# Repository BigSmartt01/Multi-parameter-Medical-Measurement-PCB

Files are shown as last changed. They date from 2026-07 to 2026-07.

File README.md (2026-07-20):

# Multi-Parameter Patient Monitoring System

**Project Topic:** Design and Development of a Multi-Parameter Patient Monitoring System with ECG Arrhythmia Detection, Real-Time Data Storage, and Wireless Remote Display.

This repository holds the hardware design (schematic, PCB, footprints, fabrication files) for the patient-side sensor and actuator unit. Firmware and the ML/logic layer on the Raspberry Pi are maintained separately by the software team; this repo covers circuitry only.

## What this device does

The board sits at the patient's bedside and handles all direct sensor and actuator interfacing:

* Reads ECG (AD8232), SpO2/pulse (MAX30102), body temperature (DS18B20), and blood pressure cuff pressure (MPXHZ6400).
* Drives a pump and a solenoid/valve for the blood pressure cuff inflate/deflate cycle.
* Displays local status on a 2.4" OLED and gives audible alerts through a buzzer.
* Streams sensor data wirelessly and receives commands over WiFi/MQTT.

The Raspberry Pi 5 sits on the nurse side, runs the ML model (arrhythmia detection), logic, data storage, and drives an HDMI display plus a web app. It never touches the patient directly, all sensor/actuator interfacing is the ESP32's job.

## System architecture (high level)

```
\[Patient side]                              \[Nurse side]
ESP32 (sensors + actuators + OLED + buzzer)  <--MQTT/WiFi-->  Raspberry Pi 5 (ML, logic, storage, HDMI, web app)
```
<p align="center">
    
</p>

MQTT topic structure (for reference, implemented in firmware):

Pi publishes (commands to ESP32):

* `pi/control/pump`
* `pi/control/valve`
* `pi/display/oled`
* `pi/control/buzzer`

Pi subscribes (data from ESP32):

* `esp32/sensors/ecg`
* `esp32/sensors/bp`
* `esp32/sensors/temp`
* `esp32/sensors/pulse`
* `esp32/status/pump`

A full block diagram will be added to `docs/` covering both the electrical and system-level data flow.

## Repository structure

```
Multi-parameter Medical Measurement/
|-- libraries/
|     |-- 3d          (3D models for footprints, if used)
|     |-- footprints   (custom KiCad footprints, e.g. module outlines)
|     |-- symbols      (custom KiCad symbols for breakout modules)
|-- fabrication         (gerbers, drill files, BOM, pick-and-place, for JLCPCB)
|-- kicad                (project file, schematic, PCB layout)
|-- docs                 (this documentation, block diagrams, reference notes)
```

## Hardware summary

|Subsystem|Part|Notes|
|-|-|-|
|MCU|ESP32 DevKit V1 (30 GPIO)|Mounted on female header for clearance|
|ECG|AD8232 breakout|LO+/LO- leads-off detection wired in|
|SpO2 / Pulse|MAX30102 breakout|I2C|
|Temperature|DS18B20|1-Wire, 4.7k pull-up|
|Blood pressure|MPXHZ6400AC6T1|SOIC-8, resistor divider scales output for ESP32 ADC|
|Display|2.4" OLED, SPI, 7-pin|CS tied to GND (only SPI device on board)|
|Alert|Piezo buzzer|Driven through BC337 NPN transistor stage|
|Pump|12V, MOSFET-switched|IRLB8721, flyback diode, gate pull-down|
|Solenoid/Valve|12V, MOSFET-switched|IRLB8721, flyback diode, gate pull-down|
|Power|3x 18650 (3S) + BMS|12.6V nominal, LM2596 module steps down to 5V|

Full pin mapping and design rationale are in [`docs/circuit\_documentation.md`](docs/circuit_documentation.md).

<p align="center">
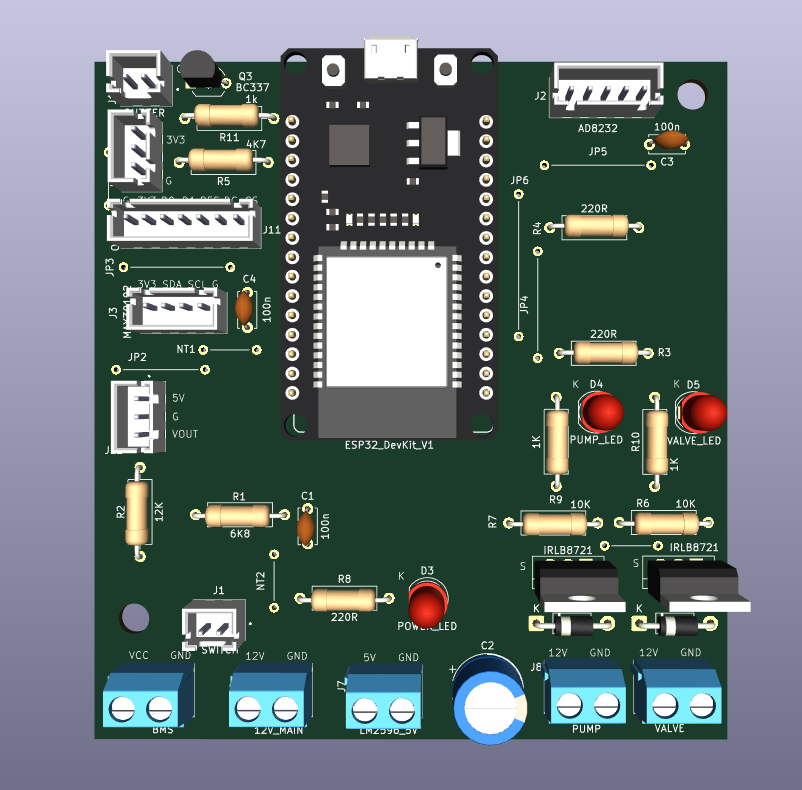
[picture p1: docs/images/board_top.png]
  <br>
  <em>Fabricated single-layer patient-side monitoring board</em>
</p>

## Power architecture

<p align="center">
  
</p>

<p align="center">
  <em>3x 18650 (3S) + BMS -> LM2596 buck -> 5V rail</em>
</p>

## Getting started

1. Open `kicad/Multi-parameter Medicals.kicad\_pro` in KiCad 9.0.7 or later.
2. Custom symbols and footprints for breakout modules (AD8232, MAX30102, LM2596 module, BMS module) live under `libraries/`, make sure these are added to your project's library table before opening the schematic, or KiCad will show missing symbol/footprint errors.
3. The board is single-layer, routed with net ties and jumper wires (JP1-JP6, NT1-NT3) to work around single-layer constraints. If you're re-routing, keep the ground pour intact between the analog sensor section (left side) and the motor/switching section (right side), see the documentation for why.
4. Before sending to fab, run a full DRC pass and verify trace widths on the high-current nets (battery/BMS input, pump, solenoid) against actual component current ratings.

## Team

Circuit design (schematic + PCB): Smart Ayodele
Firmware and ML/logic: student team

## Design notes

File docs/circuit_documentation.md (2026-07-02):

# Circuit Documentation: Multi-Parameter Patient Monitoring System

This document explains the schematic and PCB design decisions for the patient-side hardware unit. It's meant as a reference for anyone working on this board, whether debugging, modifying, or just trying to understand why something was wired the way it was.

Project topic: Design and Development of a Multi-Parameter Patient Monitoring System with ECG Arrhythmia Detection, Real-Time Data Storage, and Wireless Remote Display.

---

## 1. System overview

The board is the patient-facing sensor and actuator unit. It does not run any ML logic, does not store data long-term, and does not drive the main display, all of that is handled by a Raspberry Pi 5 on the nurse side. The ESP32 on this board's only jobs are:

1. Read four physiological parameters (ECG, SpO2/pulse, temperature, blood pressure via cuff).
2. Control the pump and solenoid/valve for the BP cuff inflate/deflate cycle.
3. Show local status on an OLED and sound a buzzer for local alerts.
4. Talk to the Raspberry Pi wirelessly (WiFi/MQTT), sending sensor data out and receiving control commands in.

Communication between the ESP32 and the Raspberry Pi is entirely wireless, so it does not add any circuitry to this board, it's handled by the ESP32's onboard WiFi.

---

## 2. Power architecture

```
3x 18650 (series) --> 3S BMS --> Push Button Switch --> [12V rail]
                                                            |
                                                            +--> Pump / Solenoid (via MOSFETs)
                                                            |
                                                            +--> Pump LED, Solenoid LED
                                                            |
                                                            +--> LM2596 buck module --> [5V rail]
                                                                                          |
                                                                                          +--> ESP32 VIN
                                                                                          +--> MPXHZ6400 pressure sensor
                                                                                          +--> Power LED

ESP32 onboard 3.3V LDO --> [3V3 rail] --> AD8232, MAX30102, DS18B20, OLED, Buzzer
```

**Why this split:** The pump and solenoid are the highest current draw items on the board and run directly off 12V rather than through the buck converter, this keeps the LM2596 sized only for what the 5V rail actually needs (ESP32 + pressure sensor), and avoids putting motor switching transients through the same regulator that's trying to hold a clean 5V for an analog sensor.

**BMS:** 3S configuration matches the three series 18650 cells, handles balancing and over-discharge/overcurrent protection.

**Bulk capacitance:** A 1000uF capacitor (C2) sits at the LM2596 output to absorb transients, particularly important given the pump/solenoid switching nearby can cause momentary sag on the input side that would otherwise ripple through to the 5V rail.

---

## 3. Sensor interfacing

### 3.1 ECG (AD8232) — J2

| Pin | Net | ESP32 GPIO |
|---|---|---|
| 3V3 | 3V3 | — |
| ECG_OUT | ECG signal | GPIO34 (ADC1_CH6, input-only) |
| LO- | Leads-off negative | GPIO33 |
| LO+ | Leads-off positive | GPIO32 |
| GND | GND | — |

A 100nF decoupling capacitor (C3) sits at the 3V3 supply pin of J2, added specifically because this board also carries motor-switching circuitry, the cap is local insurance against supply noise reaching the ECG front end.

**LO+/LO- matter.** These are digital outputs from the AD8232 that go HIGH when an electrode has detached from the skin. Without reading them, a loose lead produces garbage or flatline data indistinguishable from an actual reading, both for the arrhythmia detection model and for anyone monitoring the signal. They're read as simple digital HIGH/LOW inputs in firmware.

### 3.2 SpO2 / Pulse (MAX30102) — J3

I2C device, shares the bus with nothing else on this board (OLED is SPI, not I2C).

| Pin | Net | ESP32 GPIO |
|---|---|---|
| 3V3 | 3V3 | — |
| SDA | I2C data | GPIO21 |
| SCL | I2C clock | GPIO22 |
| GND | GND | — |

A 100nF decoupling cap (C4) is present at the 3V3 pin, same rationale as the ECG module.

### 3.3 Temperature (DS18B20) — J4

1-Wire device.

| Pin | Net | ESP32 GPIO |
|---|---|---|
| 3V3 | 3V3 | — |
| TEMP | Data | GPIO4 |
| GND | GND | — |

R5 (4.7k) is a pull-up resistor between 3V3 and the TEMP data line, required by the 1-Wire protocol.

### 3.4 Blood pressure / cuff pressure (MPXHZ6400AC6T1) — IC1

This is a bare SOIC-8 sensor IC, not a breakout module, so it needs its own supply and signal conditioning on this board.

**Pinout note:** only VS (supply), GND, and VOUT are connected. Pins DNC_1 through DNC_5 (5 of the 8 pins) are internal device connections per the datasheet and must not be connected to anything, including ground.

**Signal conditioning:** the sensor's raw output swings up to roughly 4.7V at full scale (5V supply), which exceeds the ESP32 ADC's 3.3V input limit. A resistor divider scales this down before it reaches GPIO35:

```
VOUT --[R1: 6.8k]--+--[R2: 12k]-- GND
                    |
                    +-- C1 (100nF) -- GND
                    |
                    BP_OUT --> GPIO35 (ESP32 ADC, input-only)
```

At the sensor's absolute worst-case output (4.7V), this divider brings the signal down to roughly 3.0V, safely under the ADC limit even in an overpressure fault condition. The 100nF capacitor (C1) filters switching noise picked up on the line before it reaches the ADC, added specifically because of the pump/solenoid switching happening elsewhere on the board.

**Assembly note:** this is the only SMD component on an otherwise all-through-hole board. It's SOIC-8 package with 1.27mm pin pitch, hand-solderable with a normal fine-tip iron. J12 (BP_JST) is included as a fallback in case the team decides to source a pre-assembled breakout module instead of hand-soldering the bare IC, either path works with this board.

---

## 4. Actuator interfacing (Pump and Solenoid/Valve)

Both follow an identical MOSFET low-side switching pattern.

```
GPIO --[220R gate resistor]-- MOSFET Gate
                               |
GND --[10k pull-down]---------+
                               
MOSFET Drain -- Load (Pump or Solenoid) -- 12V
MOSFET Source -- GND

Flyback diode: cathode to 12V, anode to switched node (across the load)
```

| Actuator | MOSFET | Gate GPIO | Gate resistor | Pull-down | Flyback diode |
|---|---|---|---|---|---|
| Pump | Q1 (IRLB8721) | GPIO26 | R3 (220R) | R7 (10k) | D1 (1N4007) |
| Solenoid/Valve | Q2 (IRLB8721) | GPIO27 | R4 (220R) | R6 (10k) | D2 (1N4007) |

**Why IRLB8721:** logic-level MOSFET, fully enhanced well under 3.3V gate drive, so it switches cleanly straight off an ESP32 GPIO through the gate resistor without needing a separate gate driver IC.

**Why the gate pull-down (10k):** during ESP32 boot/reset, GPIOs can float momentarily. Without the pull-down, a floating gate could let the MOSFET partially conduct unintentionally. The pull-down holds the gate at GND (MOSFET off) until firmware actively drives it high.

**Why the flyback diode:** both the pump and solenoid are inductive loads. When the MOSFET switches off, the collapsing magnetic field generates a voltage spike that can exceed the MOSFET's rated drain-source voltage and destroy it. The flyback diode gives that current a safe path to circulate (cathode to 12V, anode to the switched node) rather than spiking through the MOSFET.

**Indicator LEDs:** D4 (pump) and D5 (solenoid) are wired in parallel across each load's switched node, so they light whenever that actuator is energized, no separate GPIO or logic needed. 1k current-limiting resistors (R9, R10) since these run off the 12V rail.

---

## 5. Display and alert

### 5.1 OLED (2.4", SPI, 7-pin) — J11

| Pin | Net | ESP32 GPIO |
|---|---|---|
| 3V3 | 3V3 | — |
| D0 | SPI Clock | GPIO18 |
| D1 | SPI MOSI | GPIO23 |
| RES | Reset | GPIO16 |
| DC | Data/Command | GPIO17 |
| CS | Chip Select | Tied to GND |
| GND | GND | — |

**Note on CS:** normally CS would be driven by a GPIO (GPIO5 in early revisions of this design), but since this OLED is the only SPI device on the board, CS is tied permanently to GND instead. This is standard practice for single-device SPI buses, it saves a GPIO and works because there's no bus contention to arbitrate.

### 5.2 Buzzer — J10

The buzzer is not driven directly off a GPIO. GPIO pins can't reliably source enough current for most buzzers, so it goes through an NPN transistor low-side switch:

```
3V3 -- Buzzer(+)
Buzzer(-) -- Q3 Collector (BC337)
GPIO25 --[R11: 1k]-- Q3 Base
Q3 Emitter -- GND
```

GPIO25 through the 1k base resistor is enough to saturate the BC337 and switch the buzzer on/off cleanly, without stressing the GPIO pin regardless of the buzzer's actual current draw.

---

## 6. Complete GPIO map

| GPIO | Function | Notes |
|---|---|---|
| 4 | DS18B20 temperature data | 4.7k pull-up (R5) |
| 5 | (unused — CS net grounded instead) | See OLED section |
| 16 | OLED RES | |
| 17 | OLED DC | |
| 18 | OLED D0 / SPI CLK | |
| 21 | MAX30102 SDA | I2C |
| 22 | MAX30102 SCL | I2C |
| 23 | OLED D1 / SPI MOSI | |
| 25 | Buzzer (via Q3 base) | |
| 26 | Pump gate | via R3/R7 |
| 27 | Solenoid/Valve gate | via R4/R6 |
| 32 | AD8232 LO+ | |
| 33 | AD8232 LO- | |
| 34 | AD8232 ECG output | ADC1, input-only |
| 35 | Blood pressure sensor output | ADC1, input-only, via divider |

9 functional GPIOs in active use, well within the ESP32's available pin count, leaving room for future additions.

---

## 7. PCB layout notes

### 7.1 Single-layer constraint

This board is routed on a single copper layer, using jumper wires and net ties (JP1-JP6, NT1-NT3) to bridge connections that would otherwise require a second layer. This is a deliberate cost/complexity tradeoff for a student-fabricated board, but it means routing discipline matters more than it would on a 2-layer design, particularly around ground continuity.

### 7.2 Placement zones

The board is organized into two zones kept physically separated:

- **Sensor/signal side (left):** AD8232, MAX30102, DS18B20, OLED, and their associated JST connectors.
- **Power/switching side (right/bottom):** MOSFETs, flyback diodes, gate resistors, LM2596, BMS input, screw terminals for pump/solenoid.

This separation exists to keep switching noise from the pump/solenoid MOSFETs away from the sensitive analog ECG and pulse signals. The AD8232 connector (J2) in particular was originally placed too close to the MOSFET cluster during early layout and was moved as part of the design review, keep this in mind if the board is ever re-laid-out, that adjacency is the single most noise-sensitive placement decision on the board.

### 7.3 Ground pour

A single ground pour is used across the board (not split analog/digital grounds). This works because of placement discipline rather than pour topology: high-current return paths (motor switching) are kept geometrically away from the direct line between sensor connector grounds and the main ground return, so a shared pour doesn't inject switching noise into the sensor grounds under normal operation. If ECG readings show noise correlated with pump/solenoid activity during testing, the fix is more likely a ferrite bead on the AD8232 supply line than a ground pour rework.

### 7.4 ESP32 antenna keepout

The ESP32 DevKit module has a WiFi antenna area that needs to stay clear of copper pour, traces, and components, both on this board and in whatever enclosure houses it. Check the specific antenna zone on the module's silkscreen/datasheet and maintain that keepout, this matters more here than on a typical project since the board relies on continuous bidirectional WiFi/MQTT communication.

### 7.5 Before fabrication

- Run a full DRC pass, the jumper/net-tie routing is dense in places and worth double-checking for accidental bridges or unintended opens.
- Verify trace widths on high-current nets (battery/BMS path, pump, solenoid) against the actual rated current of the pump and solenoid being used, not just an assumed default.
- Confirm mounting hole placement against the enclosure design.
- Do a 3D/clearance check, especially around densely packed clusters, to make sure hand soldering and wire access to screw terminals is realistic.

---

## 8. Bill of Materials highlights

Full BOM is exported from KiCad under `fabrication/`. Key parts requiring careful sourcing:

| Part | Why it matters |
|---|---|
| MPXHZ6400AC6T1 | SOIC-8, only 3 of 8 pins connected, verify pinout against datasheet chamfer/pin-1 marking before soldering |
| IRLB8721 (x2) | Logic-level MOSFET, confirm TO-220 pinout (G-D-S) matches datasheet, pinout can vary by manufacturer even within the same package |
| 1N4007 (x2) | Flyback diodes, orientation is safety-critical: cathode to 12V, anode to switched node |
| BC337 | Buzzer driver transistor |
| LM2596 module | Assumed to be the ready-made module (has onboard Schottky diode and inductor), not the bare IC |

---

## 9. Revision notes

Rev 1.0, dated 2026-07-01. Diode orientation, buzzer driver, and MOSFET/AD8232 placement were reviewed and corrected during design review prior to this revision. See open items in the repository README for outstanding checks before fabrication.

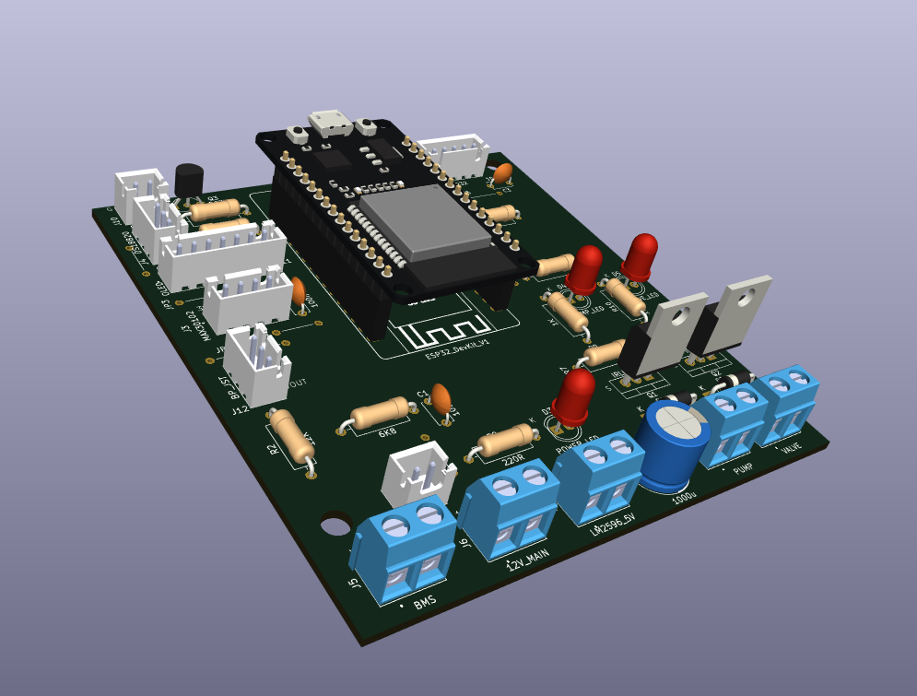
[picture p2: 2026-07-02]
docs/images/3D_04.png

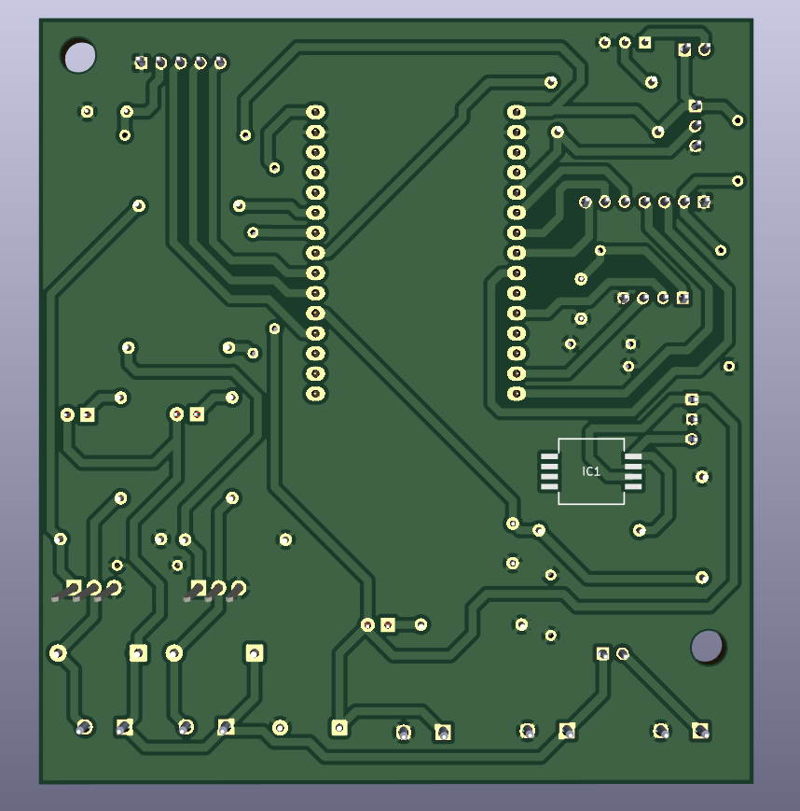
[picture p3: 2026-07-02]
docs/images/board_bottom.png

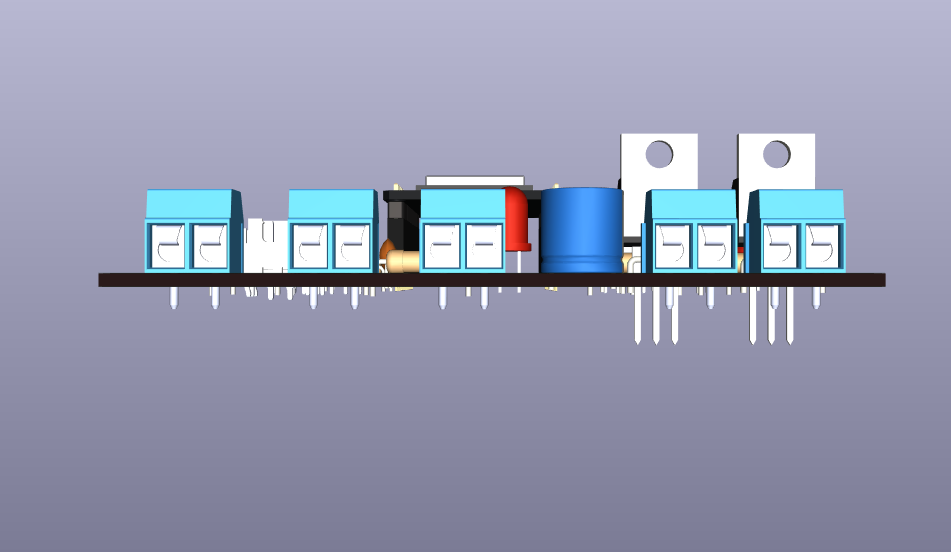
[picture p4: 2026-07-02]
docs/images/3D_03.png

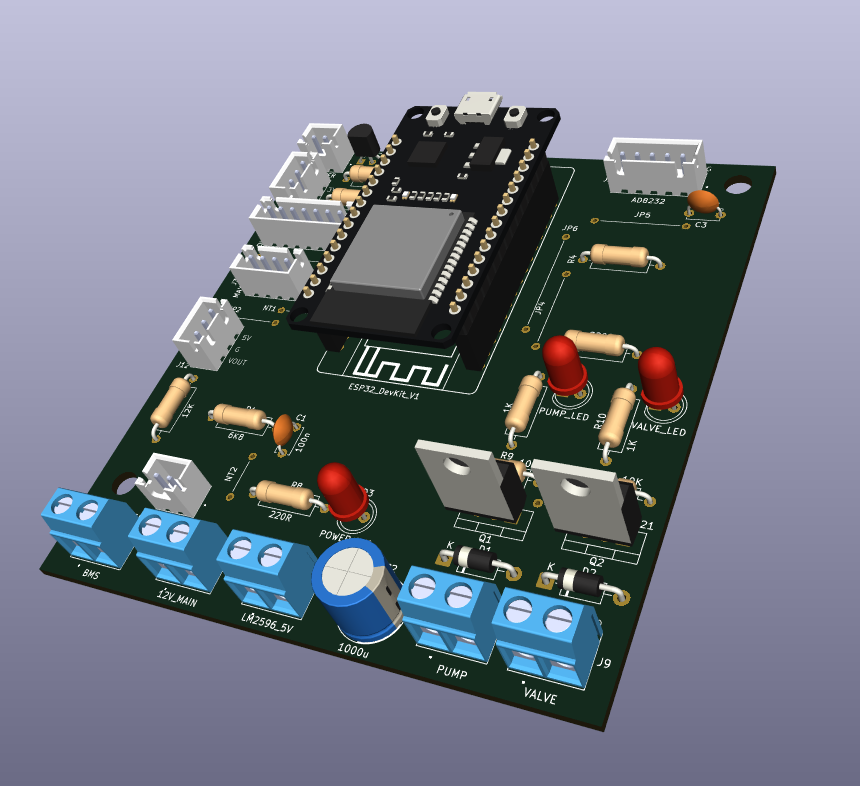
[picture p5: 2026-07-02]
docs/images/3D_05.png

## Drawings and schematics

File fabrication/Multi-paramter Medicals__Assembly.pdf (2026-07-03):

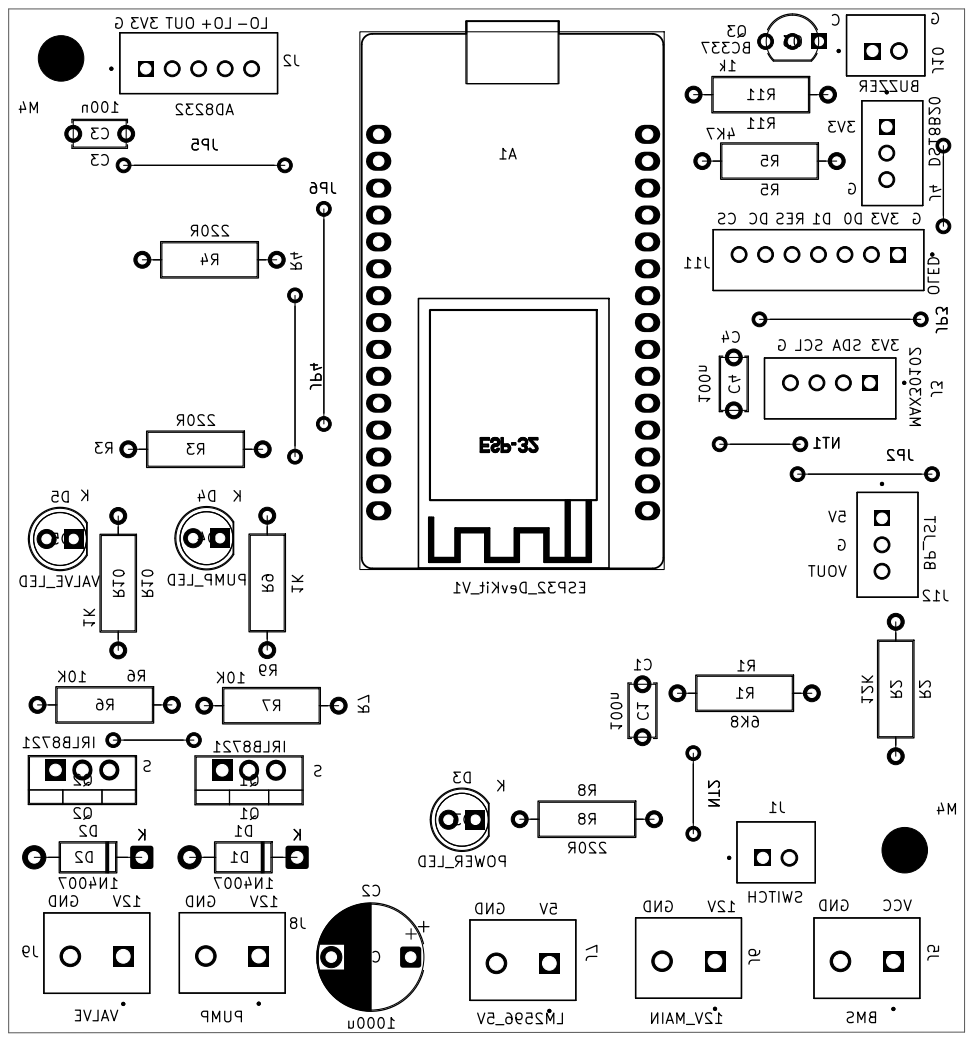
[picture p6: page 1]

Board2Pdf: Black And White TOP - Page 1/2

Sheet: Black And White TOP -----

File: Multi-paramter Medicals.kicad_pcb
Title: Multi-parameter_Medicals
KiCad E.D.A. 10.0.4

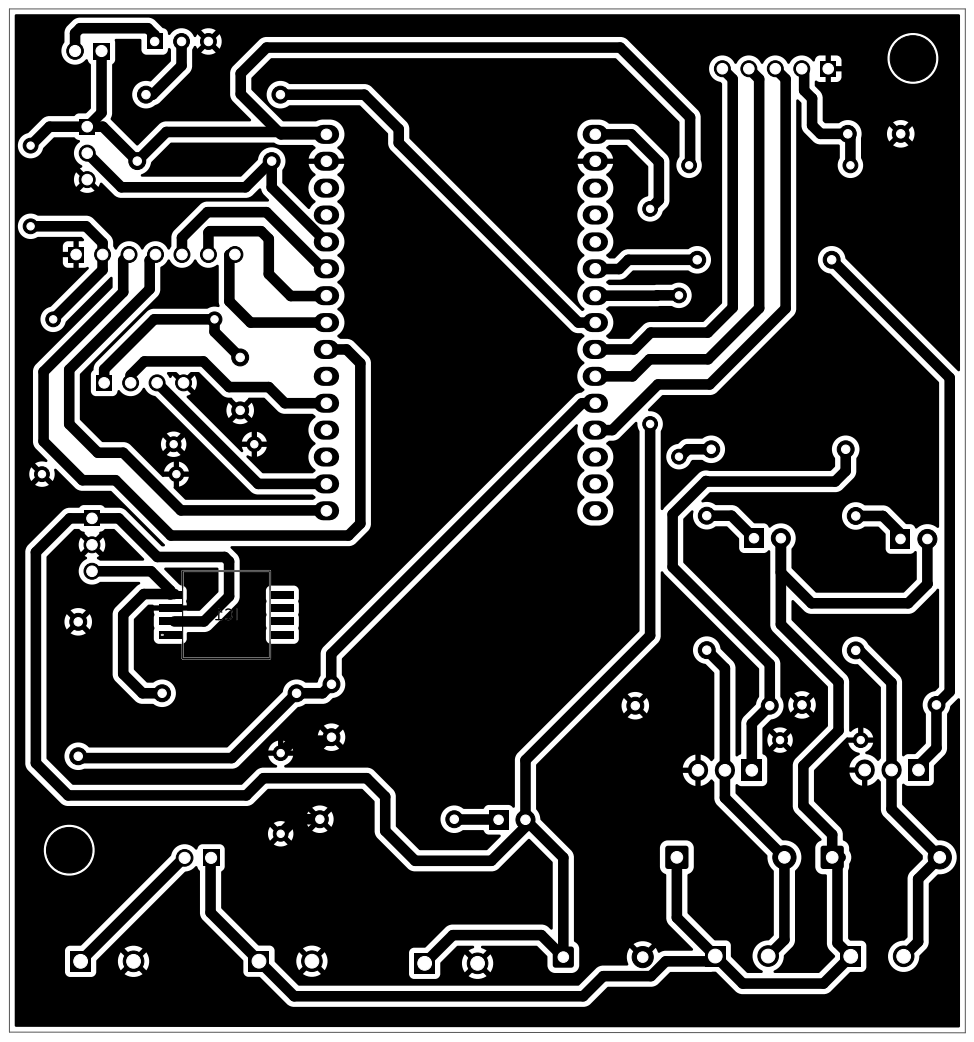
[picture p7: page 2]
D Date: 2026-07-02; Size: A4; Rev: 1.0

Board2Pdf: Black And White BOT - Page 2/2

Sheet: Black And White BOT -----

File: Multi-paramter Medicals.kicad_pcb
Title: Multi-parameter_Medicals
KiCad E.D.A. 10.0.4

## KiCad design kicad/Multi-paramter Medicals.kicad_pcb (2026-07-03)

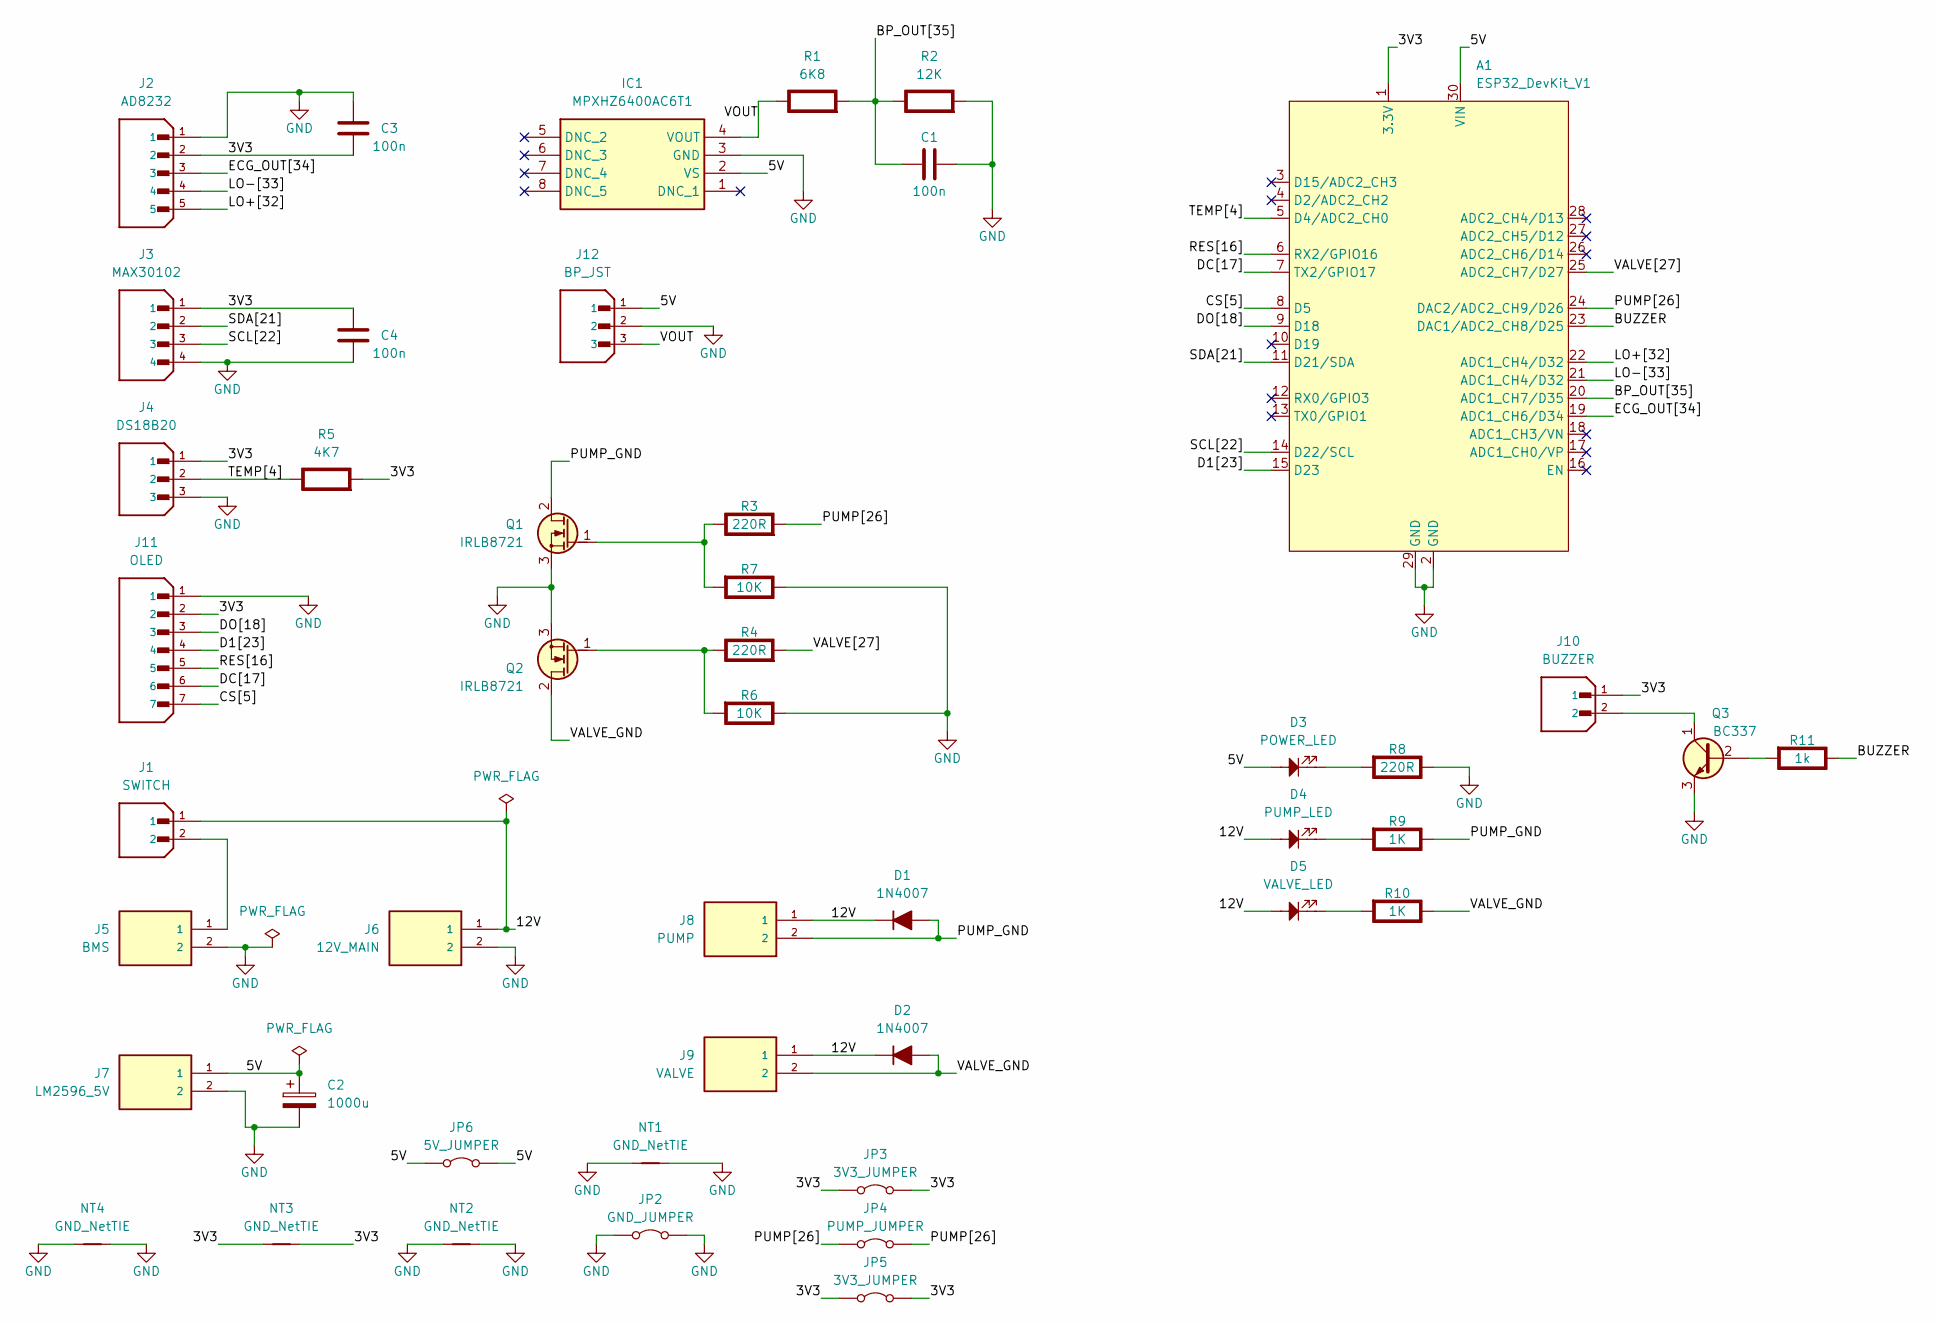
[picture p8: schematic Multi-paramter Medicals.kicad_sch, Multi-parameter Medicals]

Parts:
A1: ESP32_DevKit_V1; DOIT_ESP32_DEVKIT_30Pins
C1, C3, C4: 100n; C_Disc_D5.0mm_W2.5mm_P5.00mm
C2: 1000u; CP_Radial_D10.0mm_P7.50mm
D1, D2: 1N4007; D_DO-41_SOD81_P10.16mm_Horizontal
D3: POWER_LED; LED_D5.0mm
D4: PUMP_LED; LED_D5.0mm
D5: VALVE_LED; LED_D5.0mm
IC1: MPXHZ6400AC6T1; Manufacturer_Part_Number MPXHZ6400AC6T1; Mouser Part Number 841-MPXHZ6400AC6T1
J1: SWITCH; JST_B2B-XH-A; PARTREV N/A
J2: AD8232; JST_B5B-XH-A; PARTREV 7/4/21
J3: MAX30102; JST_B4B-XH-A; PARTREV 7/4/21
J4: DS18B20; JST_B3B-XH-A; PARTREV 7/4/21
J5: BMS; TB002-500-02BE
J6: 12V_MAIN; TB002-500-02BE
J7: LM2596_5V; TB002-500-02BE
J8: PUMP; TB002-500-02BE
J9: VALVE; TB002-500-02BE
J10: BUZZER; JST_B2B-XH-A; PARTREV N/A
J11: OLED; JST_B7B-XH-A; PARTREV 7/4/21
J12: BP_JST; JST_B3B-XH-A; PARTREV 7/4/21
JP2: GND_JUMPER; Jumper_P12.70mm_D0.7mm
JP3, JP5: 3V3_JUMPER; Jumper_P15.24mm_D0.7mm
JP4: PUMP_JUMPER; Jumper_P15.24mm_D0.7mm
JP6: 5V_JUMPER; Jumper_P20.32mm_D0.7mm
NT1, NT2, NT3, NT4: GND_NetTIE; Jumper_P7.62mm_D0.7mm
Q1, Q2: IRLB8721; TO-220-3_Vertical
Q3: BC337; TO-92_Inline_Wide
R1: 6K8; R_Axial_DIN0309_L9.0mm_D3.2mm_P12.70mm_Horizontal; Rating W
R2: 12K; R_Axial_DIN0309_L9.0mm_D3.2mm_P12.70mm_Horizontal; Rating W
R3, R4, R8: 220R; R_Axial_DIN0309_L9.0mm_D3.2mm_P12.70mm_Horizontal; Rating W
R5: 4K7; R_Axial_DIN0309_L9.0mm_D3.2mm_P12.70mm_Horizontal; Rating W
R6, R7: 10K; R_Axial_DIN0309_L9.0mm_D3.2mm_P12.70mm_Horizontal; Rating W
R9, R10: 1K; R_Axial_DIN0309_L9.0mm_D3.2mm_P12.70mm_Horizontal; Rating W
R11: 1k; R_Axial_DIN0309_L9.0mm_D3.2mm_P12.70mm_Horizontal; Rating W

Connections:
/3V3: A1.1 (3.3V), C3.2, C4.1, J2.2, J3.1, J4.1, J10.1, J11.2, JP3.1 (A), JP3.2 (B), JP5.1 (A), JP5.2 (B), NT3.1, NT3.2, R5.2 (-)
/5V: A1.30 (VIN), C2.1, D3.2, IC1.2 (VS), J7.1, J12.1, JP6.1 (A), JP6.2 (B)
/12V: D1.1 (K), D2.1 (K), D4.2, D5.2, J1.1, J6.1, J8.1, J9.1
/BP_OUT[35]: A1.20 (ADC1_CH7/D35), C1.2, R1.2 (-), R2.1 (+)
/BUZZER: A1.23 (DAC1/ADC2_CH8/D25), R11.1 (+)
/CS[5]: A1.8 (D5), J11.7
/D1[23]: A1.15 (D23), J11.4
/DC[17]: A1.7 (TX2/GPIO17), J11.6
/DO[18]: A1.9 (D18), J11.3
/ECG_OUT[34]: A1.19 (ADC1_CH6/D34), J2.3
/LO+[32]: A1.22 (ADC1_CH4/D32), J2.5
/LO-[33]: A1.21 (ADC1_CH4/D32), J2.4
/PUMP[26]: A1.24 (DAC2/ADC2_CH9/D26), JP4.1 (A), JP4.2 (B), R3.2 (-)
/PUMP_GND: D1.2 (A), J8.2, Q1.2 (D), R9.1 (+)
/RES[16]: A1.6 (RX2/GPIO16), J11.5
/SCL[22]: A1.14 (D22/SCL), J3.3
/SDA[21]: A1.11 (D21/SDA), J3.2
/TEMP[4]: A1.5 (D4/ADC2_CH0), J4.2, R5.1 (+)
/VALVE[27]: A1.25 (ADC2_CH7/D27), R4.2 (-)
/VALVE_GND: D2.2 (A), J9.2, Q2.2 (D), R10.1 (+)
/VOUT: IC1.4 (VOUT), J12.3, R1.1 (+)
GND: A1.2 (GND), A1.29 (GND), C1.1, C2.2, C3.1, C4.2, IC1.3 (GND), J2.1, J3.4, J4.3, J5.2, J6.2, J7.2, J11.1, J12.2, JP2.1 (A), JP2.2 (B), NT1.1, NT1.2, NT2.1, NT2.2, NT4.1, NT4.2, Q1.3 (S), Q2.3 (S), Q3.3 (E), R2.2 (-), R6.1 (+), R7.1 (+), R8.1 (+)
unnamed: J1.2, J5.1
unnamed: Q1.1 (G), R3.1 (+), R7.2 (-)
unnamed: Q2.1 (G), R4.1 (+), R6.2 (-)
unnamed: Q3.2 (B), R11.2 (-)
unnamed: J10.2, Q3.1 (C)
unnamed: D3.1, R8.2 (-)
unnamed: D4.1, R9.2 (-)
unnamed: D5.1, R10.2 (-)

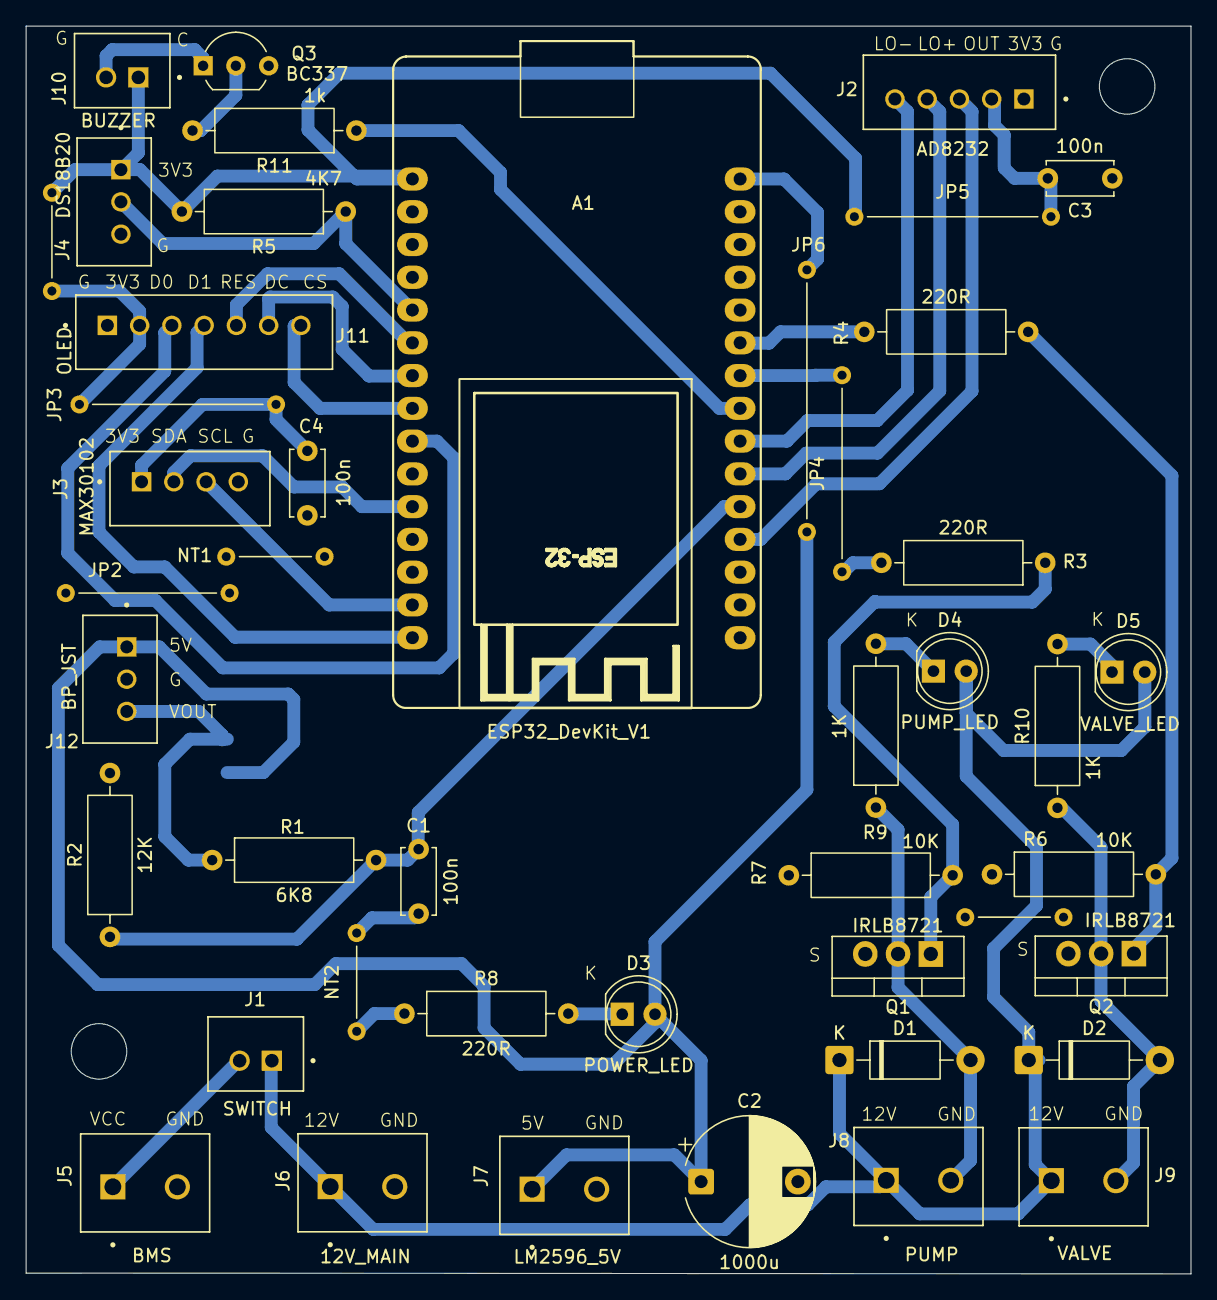
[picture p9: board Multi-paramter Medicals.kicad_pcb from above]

Board: 2 copper layers, 90.3 x 96.7 mm, 46 parts (1 on the bottom side), 30 nets.

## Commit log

2026-07-01 First push of schematics
    [Multi-paramter Medicals.kicad_pcb, Multi-paramter Medicals.kicad_sch]
2026-07-02 PCB completed
    [Multi-paramter Medicals.kicad_pcb, Multi-paramter Medicals.kicad_sch]
2026-07-03 Block diagram added with docx
    [Multi-paramter Medicals.kicad_pcb]
